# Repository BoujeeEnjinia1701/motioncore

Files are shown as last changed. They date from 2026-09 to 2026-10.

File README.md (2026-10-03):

# MotionCore

     

**Area:** Shared Components · **TRL:** 3 of 9 (proof of concept on paper) · **Value-engineering target:** USD 300 (estimated USD 293 for the kit) · **Difficulty:** 4 of 5

A standard controller and safety module (open motor controller, e-stop, speed limit and brake interlock) with a named reference hub motor, which the lab's mobility and automation designs bolt on rather than re-engineer.

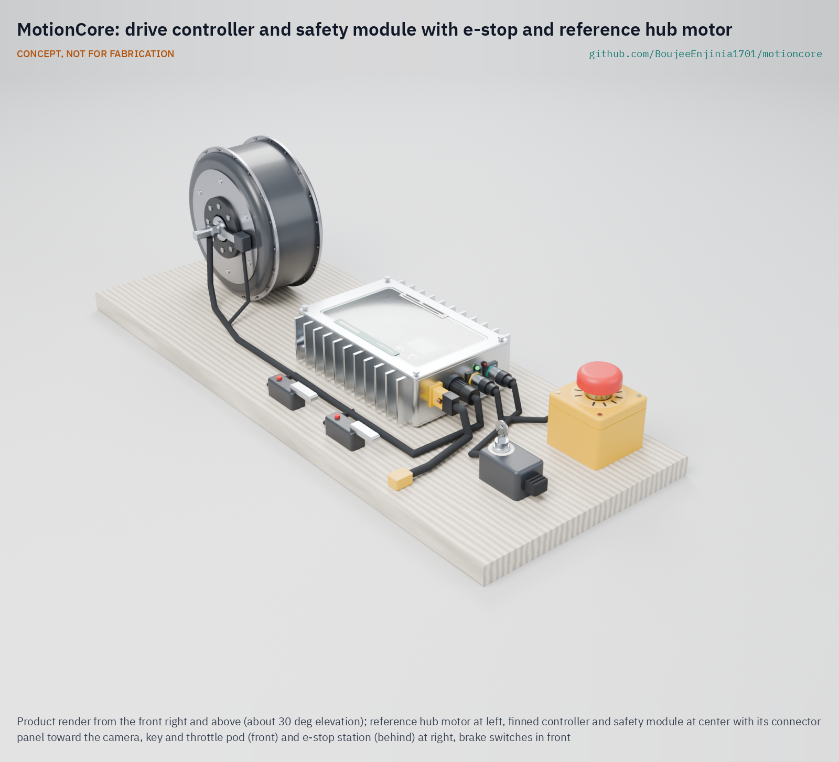
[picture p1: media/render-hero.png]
MotionCore: drive controller and safety module with e-stop and reference hub motor, product render


[Exploded render](media/render-exploded.png) · [Detail render](media/render-detail.png) · [Interactive 3D model](media/viewer.html) · [Concept blueprint (PDF)](media/concept-blueprint.pdf) · [General arrangement MTC-DWG-001 (PDF)](cad/drawings/MTC-DWG-001.pdf) · [Sizing note MTC-CAL-001](docs/04-calcs/01-sizing.md) · [Prototype build plan MTC-BLD-001](docs/05-build-plan.md) · [Design decisions MTC-DEC-001](docs/06-design-decisions.md) · [Review note](docs/REVIEW.md)

## Concept rationale

Standardizing the drive and safety chain lets the lab spend design effort on what is different about each vehicle, while every project inherits a reviewed safety function. MotionCore pairs an open VESC-class controller with a small independent supervisor and a DC contactor: the controller does the motor control it is already good at, and the supervisor and a hardwired emergency stop loop provide the second channel that low-cost controllers lack.

Keeping it open and garage-buildable matters because the people most likely to build small electric machines are makers, students and small workshops. Every part is sold off the shelf, the safety loop can be checked with a multimeter, and the interface is documented so that a host project, or anyone else, can reuse the module without closed tools.

## Burning platform

Light electric vehicles and small machines are spreading faster than the engineering support behind them. Almost 10 million electric two-wheelers were sold worldwide in 2025, about 14 % of all two-wheeler sales ([IEA Global EV Outlook 2026](https://www.iea.org/reports/global-ev-outlook-2026/trends-in-other-ev-modes)). In the United States, the Consumer Product Safety Commission estimates about 698,500 emergency department visits linked to micromobility products from 2017 through 2024 and records 533 deaths ([CPSC](https://www.cpsc.gov/s3fs-public/Micromobility_Products-Related_Deaths_Injuries_and_Hazard_Patterns_2017-2024.pdf)); most are crashes, which show how many people now ride and work beside small electric drives.

In workplaces, moving vehicles and machinery remain leading causes of death. In Great Britain, 24 of the 126 workers killed in 2025/26 were struck by a moving vehicle and 10 died in contact with moving machinery (provisional figures, [HSE](https://www.hse.gov.uk/STATISTICS/fatals-overview.htm)). An emergency stop that works without software, a speed limit that does not depend on one controller and a drive that never restarts by itself are basic protections, yet small builds often skip them.

## Where it could be used

### By industry

| Industry | Use |
| --- | --- |
| Warehousing and logistics | Drive and stop chain for powered pallet jacks, carts and tugs at walking pace (as in PalletPilot) |
| Last-mile delivery | Assist drives for cargo trailers, cargo bikes and stair-climbing hand trucks (CargoMule, StepClimber) |
| Agriculture | Small electric field carts, orchard platforms and barrows with a reliable stop |
| Solar operations and maintenance | Panel-cleaning robots and equipment carts on solar farms |
| Education and makerspaces | Teaching safe drive design with an open, inspectable safety loop |
| Rural transport | Bicycle conversion kits and shared-pack vehicles (SunSpoke with SwapCell) |

### By country or region

| Country or region | Why it matters there |
| --- | --- |
| United States | Micromobility injuries are tracked closely and rising; CPSC records 310 e-bike deaths from 2017 through 2024 ([CPSC](https://www.cpsc.gov/s3fs-public/Micromobility_Products-Related_Deaths_Injuries_and_Hazard_Patterns_2017-2024.pdf)) |
| European Union | Pedal-assist up to 250 W with a 25 km/h cutoff is excluded from type approval ([Regulation (EU) No 168/2013](https://eur-lex.europa.eu/legal-content/EN/TXT/PDF/?uri=CELEX%3A32013R0168)), so an independent speed limit matters for small builders |
| China | More than 7 million electric two-wheelers sold in 2025, over 55 % of the market ([IEA](https://www.iea.org/reports/global-ev-outlook-2026/trends-in-other-ev-modes)) |
| India | Almost 800,000 electric three-wheelers sold in 2025, almost 70 % of three-wheeler sales, many built and serviced by small workshops ([IEA](https://www.iea.org/reports/global-ev-outlook-2026/trends-in-other-ev-modes)) |
| Vietnam | About 735,000 electric two-wheelers sold in 2025, more than 20 % of the market ([IEA](https://www.iea.org/reports/global-ev-outlook-2026/trends-in-other-ev-modes)) |
| Kenya | Electric two-wheeler sales more than tripled in 2025 to over 25,000, around 15 % of new two-wheeler registrations, driven by motorcycle taxi riders ([IEA](https://www.iea.org/reports/global-ev-outlook-2026/trends-in-other-ev-modes)) |

## What sparked the idea

The idea traces back to a 2006 recall. The U.S. Consumer Product Safety Commission and Segway recalled about 23,500 Segway personal transporters because the machine could unexpectedly apply reverse torque to its wheels and throw the rider; six injuries to heads and wrists were reported, and the fix was a software upgrade ([CPSC recall notice](https://www.cpsc.gov/Recalls/2006/segway-inc-announces-recall-to-repair-segway-personal-transporters)). The recall shows how the safety of a small electric vehicle can hinge on one controller's software. MotionCore starts from the opposite assumption: the controller may misbehave, so an emergency stop that needs no firmware, a speed check on a separate sensor and a brake interlock sit beside it, and every host that bolts the module on inherits them.

## Problem

Each vehicle or machine concept re-specifies the same drive train and safety logic, and small teams rarely have time to get the emergency stop, speed limit and brake interlock right.

## Concept

A standard controller and safety module (open motor controller, e-stop, speed limit and brake interlock) with a named reference hub motor, which the lab's mobility and automation designs bolt on rather than re-engineer.

A finned module, 240 x 168 x 69 mm, holds an open VESC-class controller, a safety supervisor, a DC contactor and a precharge and fuse block. The emergency stop opens the contactor through a hardwired loop that works without any firmware, the speed limit is checked twice (controller and supervisor, each with its own speed signal), and the drive never restarts until the operator resets it. It runs from 20 to 60 V packs (24, 36 and 48 V classes), including SwapCell and CellGuard-managed 16S LiFePO4, and reads SwapCell or CellGuard faults over CAN.

The TRL 3 sizing note (MTC-CAL-001) gives, on paper: 250 W continuous at 40 °C ambient with about 47 °C on the case; 350 W on 24 V packs at about 56 °C, under the 60 °C limit thanks to a contactor coil economizer; motor power removed within 74 ms of an e-stop in the worst case; and an estimated MotionCore kit cost of USD 297 against a value-engineering target of USD 300 (USD 3 under), with the USD 70 reference motor costed to each host. The module weighs about 1.92 kg, inside its 2.0 kg limit. All figures are estimates, not measurements.

Full design precis: [docs/02-concept.md](docs/02-concept.md)

## Key components

- Reference 250 W geared hub motor, named in the interface and costed to each host (hosts may fit another motor within the rating)
- Open-source motor controller (VESC class, 20 to 60 V input)
- Safety supervisor board with its own speed sensor
- Hardwired twin-channel emergency stop and DC contactor, with precharge and main fuse
- Brake interlock switches
- Key switch and throttle pod (command input; CAN for host computers)
- Finned aluminum tube on a floor plate that doubles as the heat sink, on four M6 rivet-nut mounts
- Wiring harness with keyed connectors

The priced bill of materials is in [bom/bom.csv](bom/bom.csv); the parametric model is `cad/src/model.py`, with STEP and STL exports in `cad/step/` and `cad/stl/`.

## Building the prototype

The first prototype is the module bolted to a plywood bench board through its own mounting points, with the reference hub motor held by its axle in two slotted uprights so the wheel turns clear of the board, the e-stop station beside it and the brake levers and key and throttle pod on a short handlebar. The [prototype build plan](docs/05-build-plan.md) shows every component and every assembly step in pictures drawn from the model, with the checks and safety stops. Making the concept buildable changed how some parts are made and fixed, not what MotionCore does: the walls and fins are a cut length of finned extrusion on a separate floor plate, the sockets go straight through the end wall and a small fifth socket brings in the speed sensor ([MTC-DDR-003](docs/decisions/0003-design-for-construction.md)). Decisions still open are in the [design decisions register](docs/06-design-decisions.md).

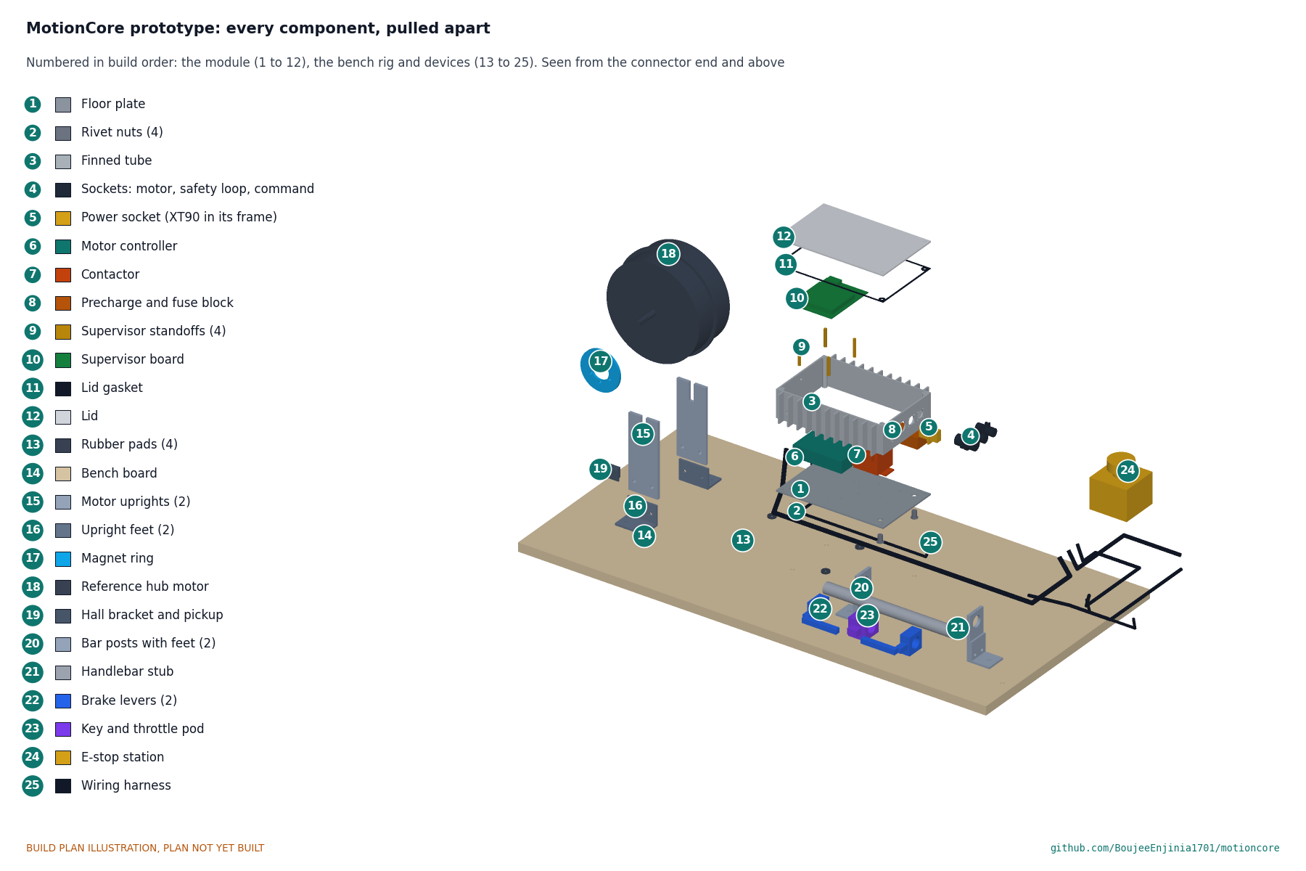
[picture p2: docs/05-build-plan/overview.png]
MotionCore prototype: every component pulled apart and numbered in build order


## Safety

> Moving machinery and stored electrical energy: guard all rotating parts, test the emergency stop before every run and limit speed during development, with the wheel off the ground for first runs. The safety functions are unverified paper designs until tested. A category 0 stop removes drive power but does not brake, so every host needs brakes that work unpowered. Never bridge the safety loop. Bus capacitors hold charge after disconnection, and the enclosure can reach about 60 °C, more in direct sun. The main fuse must be rated for the full DC pack voltage. Lithium cells can overheat, vent and burn. Use protected cells or LiFePO4, fuse every pack, charge only within the cell maker's limits and never leave a first build charging unattended. MotionCore is a research prototype, not certified to any machinery or vehicle standard. See [docs/02-concept.md](docs/02-concept.md#safety).

## Repository layout

| Folder | Contents |
| --- | --- |
| `docs/` | Problem, concept, requirements, calculations and design decisions |
| `cad/src/` | build123d Python source, the source of truth for all geometry |
| `cad/step/`, `cad/stl/` | Exported models for FreeCAD, other CAD tools and printing |
| `cad/drawings/` | 2D sketches and dimensioned drawings |
| `bom/` | Bill of materials |
| `electronics/` | KiCad schematics and PCB layouts |
| `firmware/` | Microcontroller code |
| `media/` | Renders, perspectives and photos |
| `build-log/` | Dated prototyping notes |

## Documentation

Controlled documents follow the portfolio [documentation standard](.kit/STANDARDS.md). Each carries a document ID (MTC-PRC-001 for the precis), a version and a revision history. Branded PDFs are built with `python .kit/render.py` and attached to GitHub Releases when a document is tagged, for example `MTC-PRC-001/v1.0`.

## Credits

Designed by Amish Chadha. See [CONTRIBUTORS.md](CONTRIBUTORS.md) for roles. To cite this design, use [CITATION.cff](CITATION.cff) (GitHub shows it as "Cite this repository").

AI assistance (Claude) was used to accelerate concept renders, prototype documentation and first-pass sizing calculations. Design direction and all decisions are Amish Chadha's, recorded in this repository's decision records (`docs/decisions/`).

## Licenses

- **Hardware** (CAD, drawings, BOM, electronics): [CERN-OHL-S v2](LICENSE)
- **Software** (firmware, scripts, notebooks): [MIT](LICENSE-SOFTWARE)

A project of the [Design Molecule](https://designmolecule.com) lab.

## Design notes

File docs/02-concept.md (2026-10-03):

---
doc_id: MTC-PRC-001
title: MotionCore design precis
project: MotionCore
doc_type: Design precis
version: "0.7"
status: Draft
date: '2026-10-02'
author: Amish Chadha
license: CERN-OHL-S-2.0
revisions:
- version: "0.1"
  date: '2026-09-25'
  author: Amish Chadha
  change: Initial scaffold
- version: "0.2"
  date: '2026-09-25'
  author: Amish Chadha
  change: Populate to TRL 2 (architecture, components, interface draft, first-order numbers, safety, open questions)
- version: "0.3"
  date: '2026-09-25'
  author: Amish Chadha
  change: TRL 3. Design choices adopted for TRL 3 pending Amish's review (MTC-DDR-001); motor costed to hosts; numbers checked against MTC-CAL-001; two CAN buses, precharge closure at 0.6 s, fuse and contactor criteria; model, drawing MTC-DWG-001 and media refreshed
- version: "0.4"
  date: '2026-09-25'
  author: Amish Chadha
  change: Recommendations accepted by Amish (DDR-002). Input 20 to 60 V, controller overvoltage fault 66 V, fuses rated 60 V DC or more, module mass limit 2.0 kg, XT90 provisional pending a sealed-connector evaluation; TRL 3 engineering proposals confirmed
- version: "0.5"
  date: '2026-10-01'
  author: Amish Chadha
  change: Constructable design (MTC-DDR-003, Draft, open for Amish's review). Finned tube on a floor plate, sockets through the end wall, M8 speed socket, bench rig for the prototype; size, mass and cost updated; budget as a value-engineering target
- version: "0.6"
  date: '2026-10-02'
  author: Amish Chadha
  change: "Decisions of 2026-10-02: MTC-DDR-003 accepted; interface v0.2; economizer; sealed connector rule; dual-motor and brushed hosts; license review timing"
- version: "0.7"
  date: '2026-10-02'
  author: Amish Chadha
  change: 'Interface v0.2 issued (speed socket, pin-out, host arrangements); coil economizer in the design; R2 and R9 met on paper; figures per MTC-CAL-001 v0.5'
---

# MotionCore design precis

## Summary

MotionCore is a finned aluminum module, 240 x 168 x 69 mm, that sits between a host's battery pack and its motor. Inside are an open VESC-class motor controller, a small safety supervisor board, a DC contactor and a precharge and fuse block. Outside, one keyed connector set on its end wall links it to a named reference 250 W geared hub motor, a twin-channel emergency stop, two brake switches, a key and throttle pod and an independent speed sensor. The emergency stop opens the contactor through a hardwired loop, so it works even if both processors fail. The speed limit is held twice: once in the controller and once in the supervisor, which reads its own sensor.

The TRL 3 sizing note (MTC-CAL-001) gives, on paper: 6.9 A from a SwapCell pack in the reference case, about 47 °C on the case, motor power removed within 74 ms of an e-stop (worst case), and an estimated MotionCore kit cost of USD 297 against a value-engineering target of USD 300 (USD 3 under), with the USD 70 reference motor costed to each host. The module weighs about 1.92 kg, inside the 2.0 kg limit Amish set in place of 1.5 kg (R12 met, 0.08 kg margin), and the 350 W heavy case on a 24 V pack stays under the 60 °C case limit (about 55.6 °C) because a coil economizer holds the contactor at about 1 W (R9 met on paper, in shade). The design was made buildable in MTC-DDR-003 (Draft, open for Amish's review) without changing what it does; the prototype build plan is MTC-BLD-001. The design choices below were decided by Amish on 2026-09-25, going with the recommendations (MTC-DDR-001 and MTC-DDR-002).

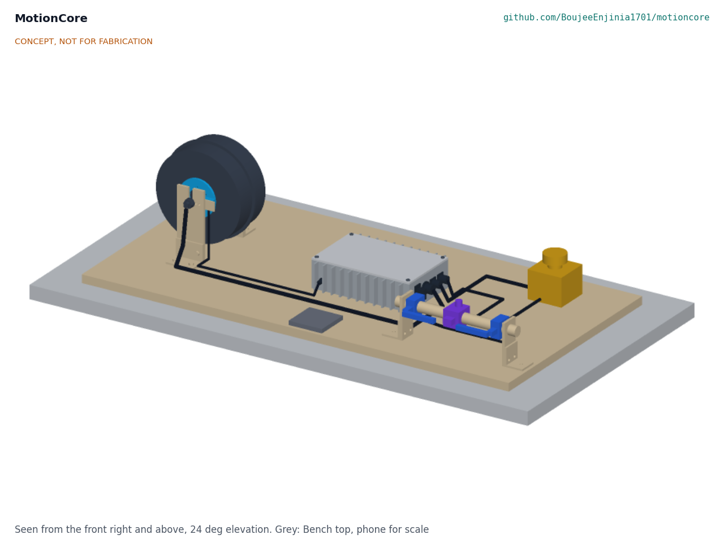
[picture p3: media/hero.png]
MotionCore concept


*Figure 1. Reference kit laid out on a bench: module (center), reference hub motor (left), e-stop station, key and throttle pod and brake switches (right). Massing-plus model, not for fabrication.*

## How it works

1. **Power up.** The pack connects through an anti-spark plug and the main fuse. The supervisor, fed from the pack through its own 18 to 75 V buck, closes the precharge path, waits six time constants (0.6 s) and checks that the controller reports at least 90 % of the pack voltage; only then may the contactor close. On a SwapCell pack the supervisor first sends the SwapCell host heartbeat (host type 0, vehicle, mode 2).
2. **Enable.** The contactor coil is powered through the safety loop: e-stop channel A, the enable key and a supervisor-controlled switch, all in series. E-stop channel B goes to the supervisor as a separate input. The supervisor closes its switch only if the throttle reads zero, both brake switches are released, the controller reports no fault on CAN and the BMS reports no fault. This gives R4: no automatic restart.
3. **Drive.** The host's command (throttle, pedal-assist sensor or CAN set-point from a host computer) goes to the supervisor, which passes a limited command to the controller over an internal CAN bus. The controller runs the motor with its own current, temperature and speed limits. Its battery current limit is set to the lower of the host setting and the pack's allowed discharge current.
4. **Watch.** The supervisor times the pulses from a magnet ring on the wheel hub (item 12), independent of the controller's own speed estimate. It also watches the brake switches, command timeouts, temperatures and the BMS fault frames on the external CAN bus.
5. **Stop.** A brake switch or a minor fault sets the controller command to zero within 200 ms (R5, R7). Overspeed, a failed controller heartbeat or any safety-loop fault opens the contactor (stop category 0 in IEC 60204-1 terms). Pressing the e-stop opens the coil circuit directly, without software, and at the same time tells the supervisor to command zero current. A host with a spring-applied brake has that brake powered from the same loop, so it clamps when the loop opens.

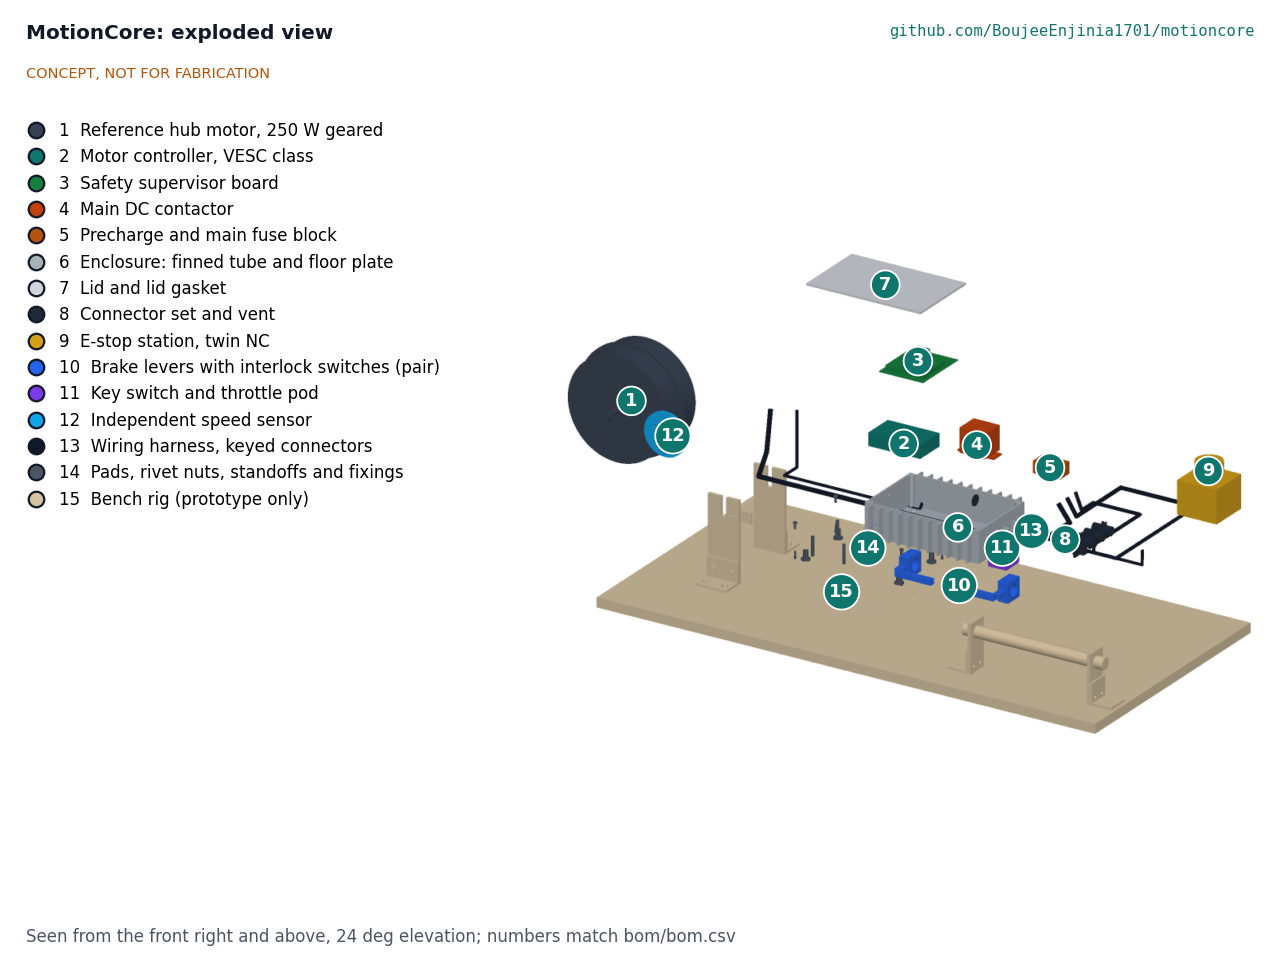
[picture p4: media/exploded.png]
Exploded view


*Figure 2. Exploded view. Numbers match `bom/bom.csv`.*

## Main components

*Table 1. Main components. Item numbers match the BOM and Figure 2.*

| Item | Component | Role |
| --- | --- | --- |
| 1 | Reference hub motor, 250 W geared | Named reference motor in the interface; costed to each host, which may substitute another motor within R2 |
| 2 | Motor controller, VESC class, 75 V stage | Field-oriented control, current and temperature limits, speed limit, CAN; overvoltage fault set to 66 V |
| 3 | Safety supervisor board | Microcontroller with two CAN buses, 18 to 75 V buck for the coil and logic, independent speed input, throttle, brake and e-stop channel B inputs, contactor enable switch, precharge switch, fault log |
| 4 | Main DC contactor, 100 A | Removes all power to the controller on e-stop or fault; coil in the safety loop; breaks at least 50 A at 60 V DC; releases within 50 ms with a 24 V Zener suppressor |
| 5 | Precharge and main fuse block | 100 Ω precharge resistor and switch; main fuse rated 60 V DC or more: 20 A for 36 and 48 V hosts, 40 A for 24 V hosts |
| 6 | Enclosure: finned tube and floor plate | Heat sink for the controller: a cut length of finned extrusion on a 3 mm floor plate; four M6 rivet nuts on a 180 x 100 mm pattern (MTC-DDR-003) |
| 7 | Lid and lid gasket | Flat 3 mm lid on a 1 mm EPDM gasket, four screws into the corner ports |
| 8 | Connector set and vent | Power in, motor, safety loop and command sockets through the end wall; M8 speed sensor socket in the side wall; membrane vent |
| 9 | E-stop station, twin NC | Red mushroom head on yellow, two normally closed contact blocks, twist release |
| 10 | Brake levers with interlock switches (pair) | Normally closed switches in each brake lever (a host may use its own lever or pedal switches) |
| 11 | Key switch and throttle pod | Enable key (reset after a stop) and a hall-effect throttle |
| 12 | Independent speed sensor | Magnet ring and Hall pickup, read only by the supervisor |
| 13 | Wiring harness, keyed connectors | Pre-made leads from the sockets to each device; 4 mm² pack leads for 24 V hosts |
| 14 | Pads, rivet nuts, standoffs and fixings | Rubber pads on the host mounting points, rivet nuts, standoffs, thermal pad, screws |

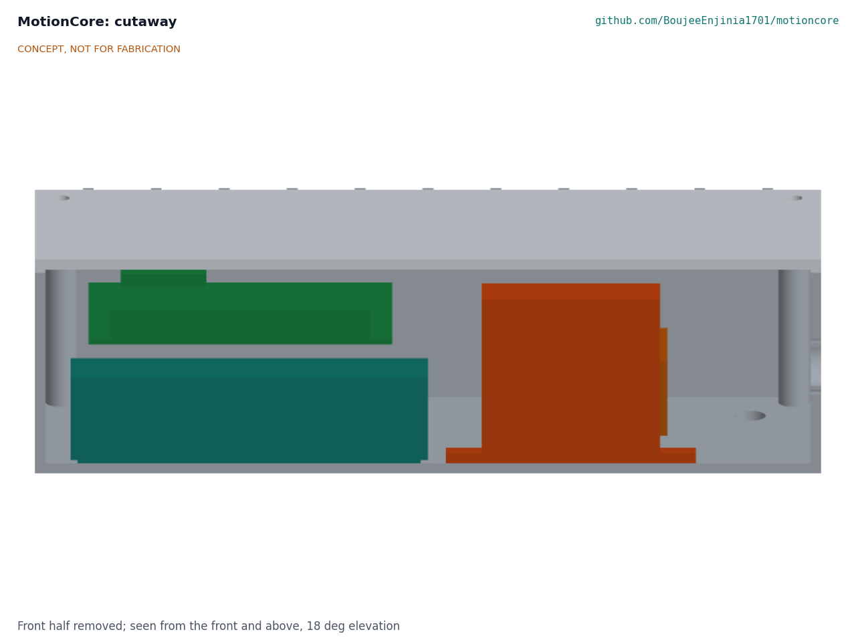
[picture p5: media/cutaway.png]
Cutaway


*Figure 3. Cutaway through the module: supervisor board on standoffs above the controller (left), contactor (center) and precharge and fuse block (right).*

### Interface (MotionCore interface v0.2)

*Table 2. Connector set (item 8). Interface v0.2 was issued on 2026-10-02 (decided by Amish, MTC-DDR-003 A1): the four sockets of v0.1 (decided 2026-09-25, MTC-DDR-001 item 6) in the +X end wall, seen from the socket side, plus an M8 4-pin speed socket in the side wall. The power connector is a sealed single-pole pair, part to be chosen (MTC-DDR-004); the XT90 shown is for the bench prototype only.*

| Connector | Type | Lines |
| --- | --- | --- |
| Power in | XT90 anti-spark plug (bench prototype only; sealed single-pole pair to follow, MTC-DDR-004) | Pack positive and negative, 20 to 60 V |
| Motor | 9-pin waterproof e-bike motor plug | Three phases, Hall sensors, motor temperature |
| Safety loop | M12 8-pin A-coded | E-stop channels A and B, brake switches A and B, enable key, brake coil output |
| Command | M12 5-pin B-coded, so it cannot mate with the safety loop | Throttle or pedal-assist, CAN high and low (external bus, 250 kbit/s), 5 V, ground |
| Speed | M8 4-pin A-coded, in the side wall | 5 V, ground, speed pulses from the independent speed sensor |

*Table 2a. Pin-out of the three signal sockets (as build plan Table 3).*

| Socket | Pin | Line |
| --- | --- | --- |
| Safety loop (M12, 8-pin A) | 1 | Loop supply, 12 V out to e-stop channel A |
| | 2 | Loop return, after e-stop channel A and the key, to the contactor coil |
| | 3 | E-stop channel B (to ground when the e-stop is not pressed) |
| | 4 | Brake switch A (to ground when the lever is released) |
| | 5 | Brake switch B (to ground when the lever is released) |
| | 6 | Brake coil output, 12 V, for a host's spring-applied brake; live only while the loop is closed |
| | 7 | Ground |
| | 8 | Not connected |
| Command (M12, 5-pin B) | 1 | +5 V for the throttle |
| | 2 | Throttle signal, 0.8 to 4.2 V |
| | 3 | Ground |
| | 4 | CAN high, external bus |
| | 5 | CAN low, external bus |
| Speed (M8, 4-pin A) | 1 | +5 V |
| | 2 | Not connected |
| | 3 | Ground |
| | 4 | Speed pulses |

The module mounts on four M6 studs on a 180 x 100 mm pattern through rubber isolation pads (drawing MTC-DWG-001). The command connector carries the external CAN bus to a SwapCell pack or a CellGuard BMS; the controller sits on a separate internal bus. The SwapCell INTERLOCK coding resistor belongs in the host's pack receptacle, not in MotionCore. Interface v0.2 has five sockets, which is one more than v0.1: CargoMule, the first host, is told of the speed socket (see the review note).

*Host arrangements (decided 2026-10-02).* Dual-motor hosts such as PalletPilot fit two controllers on one supervisor, with one safety loop and one contactor feeding both controllers. Brushed-motor hosts such as StepClimber use the VESC-class controller's DC motor mode, and need a different power stage only if the motor needs more current than the controller is rated for.

## Numbers (MTC-CAL-001)

All numbers are paper estimates printed by `docs/04-calcs/sizing.py`; nothing is measured.

### Currents and fuse

At 250 W shaft power the pack supplies about 322 W: 6.9 A at 46.8 V (SwapCell) and 8.4 A at 38.4 V (CargoMule's 12S LiFePO4 pack). The heavy case, 350 W on 25.6 V, draws 17.7 A, and 22.9 A at 20 V. For 750 W over 10 s the pack delivers 21.9 A on SwapCell and 40.9 A on 8S LiFePO4. A 20 A fuse suits 36 and 48 V hosts and a 40 A fuse suits 24 V hosts, both rated for 60 V DC or more with at least 1 kA breaking capacity (prospective short-circuit currents are about 470 to 860 A for the three packs calculated; a CellGuard 16S pack is to be checked once its resistance is known). The 100 A contactor has a wide margin on continuous current; its selection criteria are breaking at least 50 A at 60 V DC and releasing within 50 ms.

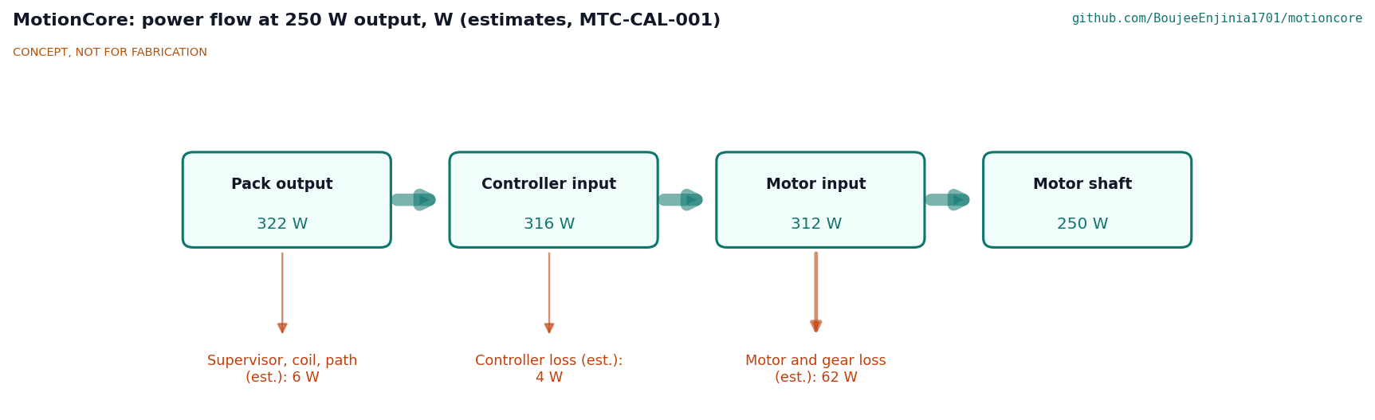
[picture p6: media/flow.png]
Power flow


*Figure 4. Estimated power flow at 250 W shaft output on a SwapCell pack (MTC-CAL-001).*

### Emergency stop timing

The e-stop contacts open the coil circuit directly. With a 24 V Zener across the coil, the modeled time to remove motor power is about 37 ms; using the 50 ms release limit that the contactor must meet, the worst case is about 74 ms, inside the 100 ms target of R3. In 74 ms a host at 25 km/h (6.9 m/s) travels about 52 cm and a walk-behind machine at 1.5 m/s about 11 cm. After that the host stops on its own brakes. A plain diode suppressor would lengthen the release; the Zener is part of the design.

### Precharge

With about 1,000 µF of bus capacitance and a 100 Ω resistor, the time constant is 0.1 s. The contactor closes after 0.6 s, when the residual difference is under 0.14 V and the closure current is at most 1.3 A. The peak precharge current is 0.55 A and the resistor absorbs about 1.5 J per start. A 1 s timeout protects the resistor if the bus is shorted.

### Thermal

The enclosure sheds about 1.16 W per kelvin of rise in still air (clear anodized, shaded).

- **Reference case:** about 6.5 W of heat in steady state (controller 4.2 W, auxiliary supply and held coil 1.9 W, power path 0.4 W at minimum pack voltage): about 47 °C at 40 °C ambient. R9 met.
- **Heavy case at 350 W:** about 16.5 W, about 55.6 °C on the walls and 56.9 °C on the floor plate, which joins the finned tube through a sealant film (MTC-CAL-001 v0.5). Met with about 4 K of margin on the walls, which would go if the controller runs hotter than modeled (62 to 68 °C in the sensitivity cases); R9 is **met on paper**, in shade. At 500 W the case would reach about 65 °C, which is why the heavy case is derated.
- **Coil economizer.** The contactor coil takes 4 W and was about half of the reference-case heat. An economizer module on the supervisor carrier board (BOM line 3), decided on 2026-10-02, applies full voltage for 0.5 s and then holds the coil at about 1 W. It is wired so the safety loop breaks the coil supply upstream of it, so a stop still drops the contactor within the 50 ms the e-stop timing assumes; its output capacitor is limited to 100 uF and the 74 ms worst case includes it.

### Speed sensing

With eight magnets and a 20 in wheel (1.57 m circumference), the supervisor sees about 7.6 pulses per second at 1.5 m/s and about 35 at 25 km/h. It times each pulse period rather than counting pulses, because a count over 0.5 s is too coarse at walking pace. Magnet placement jitter of about 2 % leaves a fivefold margin to the 10 % overspeed threshold, and a sustained overspeed opens the contactor in about 0.6 to 0.7 s.

### CAN and bus voltage

The internal bus (supervisor and controller, 500 kbit/s) runs at about 11 % load and the external bus (pack or BMS, 250 kbit/s) at about 3 %. Regeneration is off unless a host enables it, in which case the supervisor requests SwapCell mode 4 with a host charge limit. The controller's overvoltage fault sits at 66 V, above a full CellGuard 16S pack (58.4 V); if the contactor opens during regeneration it keeps the bus near 67.8 V, inside its 75 V rating. Direct-drive motors must not be pushed beyond about 1.25 times their no-load speed at 60 V without a bus clamp.

### Size, mass and cost

- Module: 240 x 168 x 69 mm; about 1.92 kg, of which the enclosure metal is about 1.0 kg. R12 (2.0 kg, relaxed from 1.5 kg by MTC-DDR-002) is met with 0.08 kg of margin. Kit: about 5.3 kg with the reference motor, 2.9 kg without.
- Cost: value-engineering target USD 300. Estimated cost of the constructable MotionCore kit (BOM items 2 to 14): USD 297 (USD 3 under the target, including USD 4 for the coil economizer module); the reference motor adds USD 70 and is costed to each host, and the prototype's bench rig USD 35 (`bom/bom.csv`).

## Key design choices

All choices below were decided by Amish on 2026-09-25, going with the recommendations (MTC-DDR-001, MTC-DDR-002).

1. **VESC-class controller rather than a custom power stage.** It is open, widely sold, already handles DC, BLDC and FOC motors and has CAN. The drawback is that it has no separate safety channel, which the supervisor and contactor provide.
2. **Contactor as the power-removal element.** A DC contactor is cheap, visible and testable with a multimeter. Safe Torque Off on the gate drivers would be faster and wear-free but needs a custom controller.
3. **Separate supervisor with its own speed sensor.** This gives two independent channels for speed limiting, following the structure of ISO 13849-1 Category 3 without claiming a performance level.
4. **Stop category 0 by default.** Removing power is simplest to verify. Category 1 (brake electrically, then open the contactor) is a per-host option for heavier hosts.
5. **Wide input range (20 to 60 V).** One module serves 24, 36 and 48 V hosts, including CellGuard's 16S LiFePO4 packs at 58.4 V full; DustRunner's 12.8 V system stays out of scope.
6. **Motor as a named reference part, costed to hosts.** The interface names the reference motor, but the USD 300 value-engineering target covers the module and devices only.
7. **Supervisor as SwapCell host and CellGuard reader.** The supervisor sends the SwapCell heartbeat and removes torque on a BMS fault.
8. **Heavy case derated to 350 W on 24 V packs.**
9. **Separate firmware.** Unmodified GPL-3.0 VESC firmware on the controller and MIT supervisor firmware on its own processor, linked only by CAN.

10. **Module mass limit 2.0 kg.** The enclosure stays as drawn, because it is the heat sink and R9 depends on it.
11. **TRL 3 engineering rules from MTC-CAL-001.** Two CAN buses on the supervisor, precharge closure at 0.6 s with a 90 % bus check, fuses rated for the full DC range with 1 kA breaking capacity, 4 mm² pack leads for 24 V hosts and a 24 V Zener coil suppressor. The fuse rating became 60 V DC and the controller overvoltage fault 66 V (instead of 58 V and 60 V) when R1 was raised to 60 V.
12. **Sealed power connector evaluated (MTC-DDR-004).** The XT90 stays in the model and drawing as the bench prototype's part until a sealed connector is chosen.

Decisions are recorded in [decisions/](decisions/).

## Safety

> **Safety:** MotionCore drives moving machinery from a lithium pack. Guard all rotating parts, test the emergency stop before every run and limit speed during development. The pack can deliver several hundred amperes into a short circuit (about 470 to 860 A for the host packs considered): fuse it with a fuse rated for the full DC voltage, use the anti-spark connector, and never work on the module with the pack connected. Bus capacitors can hold charge after disconnection; wait and measure before touching the board. The enclosure can reach about 50 to 60 °C in hot conditions, more in direct sun. Opening a contactor under DC load can arc; use a contactor rated for DC breaking at the full pack voltage. Lithium cells can overheat, vent and burn: use packs with a BMS, fuse every pack and never leave a first build charging unattended.

- **Unverified safety function.** Until tested at TRL 4, which is on hold, the e-stop timing, overspeed trip and restart inhibit are paper claims. First runs should be on a bench with the wheel off the ground and a second person at the e-stop.
- **Coasting after a stop.** A category 0 stop removes drive power but does not brake. The host must have brakes that stop it unpowered, and walk-behind hosts need spring-applied brakes.
- **Back-EMF.** A direct-drive motor pushed faster than about 1.25 times its no-load speed (at 60 V) can raise the bus above 75 V through the controller's MOSFET body diodes, even with the contactor open. Geared hubs with a freewheel avoid this; direct-drive hosts need a speed limit or a bus clamp.
- **Configuration errors.** The speed limit depends on the wheel circumference and magnet count stored in the supervisor. A wrong value moves the limit; the fault chart must say so.
- **Misuse of the interface.** If the safety loop is bridged with a jumper, every protection is lost. The loop connector is keyed and the fault chart must say so plainly.
- **No certification.** MotionCore is a research prototype. It is not certified to ISO 13849, IEC 60204-1, EN 15194 or any vehicle rule, and it does not make a host compliant.

## Open questions

- Dual-motor hosts (PalletPilot): decided 2026-10-02, two controllers on one supervisor, with one safety loop and one contactor feeding both, so a stop removes torque from both wheels at once.
- Brushed motors (StepClimber): decided 2026-10-02, the controller's DC motor mode; a different stage only if StepClimber's motor needs more current than the controller is rated for.
- Which sealed power connector replaces the unsealed XT90 (R10): the paper evaluation is written (MTC-DDR-004); it recommends an industrial IP67 single-pole pair, two receptacles with different key coding, and chooses no part, because the rule (keyed, IP67 when mated, 40 A or more continuous at 60 V DC, no exposed live contacts on the pack side) has to be checked against a named part's datasheet at the parts purchase. The XT90 stays for the bench prototype only; R10 stays at risk.
- Contactor coil economizer: decided 2026-10-02 and now in the design: a module on the supervisor carrier board (BOM line 3, USD 4), wired after the safety loop's break in the coil supply; heavy case 55.6 °C on the walls instead of 58.4 °C (MTC-CAL-001 v0.5).
- Whether a pack in SwapCell legacy discharge accepts a heartbeat and moves to mode 2 without opening its output; raised with SwapCell.
- License boundary between the VESC firmware (GPL-3.0) and the MIT supervisor firmware: the short written review is done (MTC-DDR-005), with a firmware readme to be written before any firmware is published; a lawyer only if a commercial partner will ship the module (decided 2026-10-02).

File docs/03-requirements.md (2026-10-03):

---
doc_id: MTC-REQ-001
title: MotionCore requirements
project: MotionCore
doc_type: Requirements
version: "0.7"
status: Draft
date: '2026-10-02'
author: Amish Chadha
license: CERN-OHL-S-2.0
revisions:
- version: "0.1"
  date: '2026-09-25'
  author: Amish Chadha
  change: Initial scaffold
- version: "0.2"
  date: '2026-09-25'
  author: Amish Chadha
  change: First measurable requirements for TRL 2, with status against the concept estimates
- version: "0.3"
  date: '2026-09-25'
  author: Amish Chadha
  change: TRL 3. R2 heavy case relaxed to 350 W and R14 redefined to the MotionCore kit without the motor (MTC-DDR-001, adopted for TRL 3 pending Amish's review); status column from MTC-CAL-001
- version: "0.4"
  date: '2026-09-25'
  author: Amish Chadha
  change: Recommendations accepted by Amish (DDR-002). R1 upper bound 58 to 60 V; R12 mass limit 1.5 to 2.0 kg; status from MTC-CAL-001 v0.2
- version: "0.5"
  date: '2026-10-01'
  author: Amish Chadha
  change: Constructable design (MTC-DDR-003); status from MTC-CAL-001 v0.3 (R9, R11, R12); R14 reported against the value-engineering target; no status changed
- version: "0.6"
  date: '2026-10-02'
  author: Amish Chadha
  change: "Decisions of 2026-10-02 noted: interface v0.2 (R11), economizer (R9), sealed connector evaluation (R10), license review timing (R13); no status changed"
- version: "0.7"
  date: '2026-10-02'
  author: Amish Chadha
  change: 'Status from MTC-CAL-001 v0.5: R2 and R9 re-rated to met on paper with the coil economizer; R3, R12 and R14 figures updated'
---

# MotionCore requirements

These requirements are checked by calculation in MTC-CAL-001 v0.5, against the constructable design of MTC-DDR-003. Four targets have changed since TRL 2, all decided by Amish on 2026-09-25 (MTC-DDR-001 and MTC-DDR-002): the heavy case in R2 is 350 W instead of 500 W; R14 covers the MotionCore kit without the reference motor; the upper bound of R1 is 60 V instead of 58 V, so that CellGuard's 16S LiFePO4 packs are covered; and the mass limit in R12 is 2.0 kg instead of 1.5 kg, because the enclosure is also the heat sink. No requirement has been verified by test.

The **reference case** used throughout is a 250 W geared hub motor on a 48 V (46.8 V nominal) SwapCell pack at 40 °C ambient. The **heavy case** is 350 W continuous on a 25.6 V (8S) LiFePO4 pack at 40 °C ambient.

On paper, twelve requirements are met and none is not met. R10 is **at risk**; R11 cannot be verified at TRL 3. R2 and R9 moved from at risk to met on paper on 2026-10-02 because the contactor coil economizer is now in the design. R12 is met with a margin of 0.08 kg.

*Table 1. Requirements.*

| ID | Requirement | Target | Verification (TRL 3 or later) | Status at TRL 3 (MTC-CAL-001) |
| --- | --- | --- | --- | --- |
| R1 | Supply range | Operate from 20 to 60 V DC (8S LiFePO4 to 13S lithium-ion and 16S LiFePO4, including SwapCell at 54.6 V full and CellGuard 16S at 58.4 V full); withstand 75 V transients from regeneration | Controller and contactor datasheets; bus voltage calculation | Met (design review): 75 V controller, 18 to 75 V auxiliary buck, bus peaks near 67.8 V with a 66 V controller overvoltage fault |
| R2 | Motor power | 250 W continuous in the reference case; 350 W continuous in the heavy case; 750 W for 10 s | Current and thermal calculation | Met on paper (re-rated 2026-10-02): 6.9 A, 17.7 A; 750 W peak 21.9 A on SwapCell, 40.9 A on 8S LiFePO4; the heavy case now holds with R9 |
| R3 | Hardwired emergency stop | Twin-channel normally closed e-stop wired in series with the contactor coil; motor power removed within 100 ms of actuation; works with the supervisor and controller both failed | Circuit review; contactor drop-out time from datasheet | Met on paper: 74 ms worst case, 37 ms modeled (including the coil economizer's output capacitor); unverified |
| R4 | No automatic restart | After an e-stop, power loss or fault, the drive stays off until the e-stop is released, the throttle is at zero and the operator cycles the enable key | Circuit and state-machine review | Met (design review); unverified |
| R5 | Brake interlock | Two brake switch inputs; drive torque removed within 200 ms of either switch opening; a spring-applied brake output released only while the safety loop is closed | Circuit review; supervisor timing budget | Met on paper: about 75 ms; unverified |
| R6 | Independent speed limit | Speed limit set in the controller and checked by the supervisor from a separate sensor; overspeed of more than 10 % for more than 0.5 s opens the contactor; defaults 25 km/h (pedal assist) and 1.5 m/s (walk-behind) | Firmware review; sensor resolution calculation | Met on paper: period timing, fivefold margin over magnet jitter, trip in 0.60 to 0.70 s; unverified |
| R7 | Fault reaction | Supervisor removes torque within 200 ms of: command timeout, throttle signal outside 0.5 to 4.5 V, loss of controller CAN heartbeat, over-temperature or BMS fault flag | Fault table review | Met on paper: about 170 ms worst (controller heartbeat), about 80 ms for a BMS fault; unverified |
| R8 | Precharge | Inrush at contactor closure under 5 A; bus ready within 1 s | Precharge calculation | Met: 0.55 A peak, 1.3 A at closure, ready in 0.6 s |
| R9 | Thermal | Enclosure surface 60 °C or less at 40 °C ambient in natural convection | Thermal calculation | Met on paper (re-rated 2026-10-02) in shade: reference case 47.0 °C; heavy case 55.6 °C on the walls and 56.9 °C on the floor plate with the contactor coil economizer in the design (BOM line 3); the sensitivity cases reach 62 to 68 °C, so the margin rests on the controller assumptions |
| R10 | Ingress and vibration | Enclosure and mated connectors IP65; survive road and stair vibration without loosening | Datasheets and design review | **At risk:** the XT90 power socket is not sealed; a sealed power connector is to be evaluated before interface v0.1 is frozen (MTC-DDR-002). Decided 2026-10-02: the paper evaluation is done now against a rule (keyed, IP67 mated, 40 A or more continuous at 60 V DC, no exposed live contacts on the pack side; first candidate class an industrial IP67 single-pole connector such as Amphenol's SurLok Plus), and the XT90 stays for the bench prototype only; vibration not analyzed |
| R11 | One interface | One documented connector set (power in, motor, sensors, safety loop, command) keyed against mis-mating; fitted to a new host in 2 h or less with hand tools | Interface document; timed fit at TRL 4 | Not verifiable at TRL 3: interface v0.2 decided on 2026-10-02 (MTC-DDR-003 A1): the four sockets of v0.1 drawn in MTC-DWG-001 Rev P3 plus an M8 4-pin speed sensor socket, with the pin-out of build plan Table 3 |
| R12 | Size and mass | Module within 250 x 170 x 70 mm; module mass 2.0 kg or less (1.5 kg before MTC-DDR-002) | Model and mass estimate | Met: 240 x 168 x 69 mm; about 1.92 kg, 0.08 kg margin |
| R13 | Open and repairable | Hardware under CERN-OHL-S-2.0; supervisor firmware MIT; controller firmware open source; fault log readable over USB without closed software | License review | Met (design review): separate programs on separate processors, CAN link only; the short written license boundary review is done (MTC-DDR-005), and a firmware readme is written before any firmware is published (decided 2026-10-02) |
| R14 | Cost | MotionCore kit (module and devices, BOM items 2 to 14) against a value-engineering target of USD 300 in parts (a hypothetical control target, not a limit); the reference motor is costed to each host | Priced BOM (`bom/bom.csv`) | USD 297 on indicative prices, USD 3 under the target (reference motor USD 70 extra) |

## Assumptions

- Motor efficiency about 80 % at rated load; controller losses from a component model (MTC-CAL-001 Table 1), which gives about 98 to 99 % controller efficiency; to be checked against datasheets once parts are chosen.
- Contactor release time 50 ms or less with a 24 V Zener coil suppressor; this is a selection criterion for the part.
- Enclosure conductance about 1.17 W/K from simplified natural convection and radiation correlations, clear anodized, shaded (MTC-CAL-001 section 4).
- The host provides mechanical brakes able to stop it with the motor unpowered. MotionCore removes drive power; it does not replace the host's brakes.
- The host carries out its own risk assessment. MotionCore targets are not a claimed ISO 13849 performance level.

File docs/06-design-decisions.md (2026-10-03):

---
doc_id: MTC-DEC-001
title: MotionCore design decisions register
project: MotionCore
doc_type: Design decisions register
version: "0.3"
status: Draft
date: '2026-10-02'
author: Amish Chadha
license: CERN-OHL-S-2.0
revisions:
  - version: "0.1"
    date: '2026-10-01'
    author: Amish Chadha
    change: Register opened with the build plan; open items from REVIEW.md, MTC-DDR-001 to 003 and the build work; budget treated as a value-engineering target
  - version: "0.2"
    date: '2026-10-02'
    author: Amish Chadha
    change: "Amish approved the recommendations for open decisions 1 to 9 (2026-10-02); moved to decisions made (MTC-DDR-003 accepted)"
  - version: "0.3"
    date: '2026-10-02'
    author: Amish Chadha
    change: 'Follow-ups carried out: economizer in BOM and model (kit USD 297); sealed connector evaluation and license boundary review written (MTC-DDR-004, MTC-DDR-005); item to confirm for the connector part'
---

# MotionCore design decisions register

Every design decision still to be made, and every decision made, in one place. Each decision is argued in full in its decision record under `docs/decisions/`; this register is the index Amish works from. The build plan (`docs/05-build-plan.md`) describes the design as it stands and does not list open decisions.

## Open decisions

None. All open decisions were decided on 2026-10-02.

## To confirm when parts are bought

| # | What to confirm | Why it matters | Source |
| --- | --- | --- | --- |
| 1 | A finned enclosure extrusion near 220 x 140 mm with 3 mm walls, vertical-running fins about 3 x 14 mm on a 19 mm pitch and four inside-corner screw ports; if none is stocked, a short custom run or a machined body | Sets the tube, the floor plate's corner holes and the thermal figures | MTC-DDR-003, P1 |
| 2 | The controller's mounting-hole pattern, flat base for the thermal pad, bus capacitance (about 1,000 µF) and MOSFET resistance | Sets the floor plate's controller holes and the precharge and thermal figures | MTC-CAL-001 section 1 |
| 3 | The contactor's foot holes, release time (50 ms or less with the Zener) and DC breaking rating (50 A at 60 V) | Sets the floor holes and the e-stop timing | MTC-CAL-001 section 5 |
| 4 | The reference motor's axle width (about 135 mm), axle flats (10 mm) and six-bolt disc mount | Sets the upright spacing and slot, and the magnet ring | MTC-DDR-003, P10, P11 |
| 5 | Brake levers with normally closed (not normally open) cut-off switches | The interlock expects a closed contact when released | MTC-PRC-001 item 10 |
| 6 | The M12 sockets come with 20 mm four-screw square flanges and the XT90 with a two-screw panel frame | Sets the end wall holes | MTC-DDR-003, P5 |
| 7 | The prospective short-circuit current of a CellGuard 16S pack against the fuse's 1 kA breaking capacity | Fuse choice for CellGuard hosts | MTC-CAL-001 section 3 |
| 8 | Whether a SwapCell pack in legacy discharge accepts a heartbeat and moves to mode 2 without opening its output | The supervisor is powered from the pack | `docs/REVIEW.md`, cross-repo actions |
| 9 | The sealed power connector part: the evaluation (MTC-DDR-004) recommends an industrial IP67 single-pole pair; check one named part's datasheet against the rule (keyed, IP67 mated, 40 A or more at 60 V DC, no exposed live contact), then change the end wall holes, socket frame and BOM line 8 | Sets R10 and the end wall of the tube | MTC-DDR-004 |
| 10 | The coil economizer module: a 12 V, 1 A part with full voltage for 0.5 s, then about 1 W hold and an output capacitor of 100 uF or less | Sets the 1 W hold figure of R9 and the 74 ms of R3 | MTC-CAL-001 v0.5 |

## Value engineering

Value-engineering target: USD 300 (a hypothetical control target, not a limit). Estimated cost of the constructable design: USD 297 for the MotionCore kit, items 2 to 14 (USD 3 under the target). The reference hub motor (USD 70) is costed to each host, and the bench rig (USD 35) belongs to the prototype only. Main cost drivers and savings worth trying:

- The largest lines are the controller (USD 85), the enclosure tube and floor plate (USD 30), the supervisor with its coil economizer (USD 34), the contactor (USD 25) and the connector set (USD 24).
- The contactor coil economizer (decided 2026-10-02) added USD 4 to the supervisor line.
- Making the design constructable added USD 28: the enclosure tube and floor plate (USD 8 more), the sockets with flanges and frames, the M8 speed socket and the membrane vent (USD 6), brake levers in place of bare switches (USD 6), the speed sensor's plug (USD 2), the harness branch (USD 2) and rivet nuts and fixings (USD 4).
- Savings worth trying: a stock finned extrusion close to the drawn size rather than a custom one; buying the motor, the brake levers and the pod as one e-bike kit; and, once the interface is settled, laying the supervisor out on one small circuit board in place of modules on a carrier board (TRL 4 work).

## Decisions made

| Date | Decision | Decided by | Record |
| --- | --- | --- | --- |
| 2026-09-25 | TRL 2 review items 1 to 11: budget scope (motor costed to hosts), 20 V lower bound, VESC-class controller, DC contactor, stop category 0, interface v0.1, SwapCell heartbeat, CellGuard link, 350 W heavy case, separate firmware, CargoMule as first host | Amish: "i accept all your recommendations, go with them across all repos." | MTC-DDR-001, MTC-DDR-002 |
| 2026-09-25 | R12 module mass limit relaxed from 1.5 to 2.0 kg | Amish, same instruction | MTC-DDR-002 item 15 |
| 2026-09-25 | TRL 3 engineering rules: two CAN buses, 0.6 s precharge with a 90 % bus check, DC-rated fuses with 1 kA breaking capacity, 4 mm² leads for 24 V hosts, 24 V Zener coil suppressor | Amish, same instruction | MTC-DDR-002 item 16 |
| 2026-09-25 | R1 upper bound raised from 58 to 60 V for CellGuard 16S packs (overvoltage fault 66 V, fuses 60 V DC as consequences) | Amish, same instruction | MTC-DDR-002 item 17 |
| 2026-09-25 | Evaluate a sealed power connector before interface v0.1 is frozen; XT90 provisional | Amish, same instruction | MTC-DDR-002 item 18 |
| 2026-10-01 | The budget is a value-engineering target, not a limit | Amish: "the budgets are a hypothethical control target to ensure we are thinking along a value engineering lens. its ok to ensure wording reflects that the hypothesis budget was x - the real cost being accrued is y" | `.kit/STANDARDS.md` section 18 |
| 2026-10-02 | Design for construction accepted as made: the changes P1 to P14 (finned tube on a floor plate, rivet nuts, sockets through the wall, supervisor board layout, bench rig and the others) and their knock-on changes | Amish: "i approve your recommendations for all 555 open decisions." | MTC-DDR-003, Table 1 |
| 2026-10-02 | Interface v0.2: option (a). Issue interface v0.2 with an M8 4-pin speed socket and the pin-out of build plan Table 3, and tell CargoMule, the first host, of the fifth socket | Amish: "i approve your recommendations for all 555 open decisions." | MTC-DDR-003, A1 |
| 2026-10-02 | Bench rig: option (a). Build it with the first prototype, outside the kit total (USD 35) | Amish: "i approve your recommendations for all 555 open decisions." | MTC-DDR-003, A2 |
| 2026-10-02 | Contactor coil economizer: fit it, wired so the safety loop breaks the coil supply upstream of the economizer, so a stop still drops the contactor within the 50 ms the e-stop timing assumes | Amish: "i approve your recommendations for all 555 open decisions." | MTC-DDR-002 item 19; MTC-DDR-003, A3 |
| 2026-10-02 | Sealed power connector: do the paper evaluation now against one rule (keyed, IP67 when mated, at least 40 A continuous at 60 V DC, no exposed live contacts on the pack side); first candidate class, an industrial IP67 single-pole power connector such as Amphenol's SurLok Plus. The XT90 stays for the bench prototype only | Amish: "i approve your recommendations for all 555 open decisions." | MTC-DDR-002 item 18 |
| 2026-10-02 | Dual-motor hosts (PalletPilot): two controllers on one supervisor, with one safety loop and one contactor feeding both controllers | Amish: "i approve your recommendations for all 555 open decisions." | MTC-DDR-001 item 12 |
| 2026-10-02 | Brushed motors (StepClimber): the VESC-class controller's DC motor mode; a different power stage only if StepClimber's motor needs more current than the controller is rated for | Amish: "i approve your recommendations for all 555 open decisions." | MTC-DDR-001 item 13 |
| 2026-10-02 | Appearance model: the lid window, lights, two-flange hub, layout and harness are render-only; the renders are redone on the constructable design before the repo goes public | Amish: "i approve your recommendations for all 555 open decisions." | `docs/REVIEW.md`, session of 2026-09-26 |
| 2026-10-02 | License boundary: a short written review before any firmware is published; a lawyer only if a commercial partner will ship the module | Amish: "i approve your recommendations for all 555 open decisions." | MTC-REQ-001 R13 |

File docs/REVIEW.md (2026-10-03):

# Review note: MotionCore

## Session 2026-10-01: build plan and constructable design (kit 1.7.0)

Kit 1.7.0 installed (`.kit/`, `.claude/commands/`, `CLAUDE.md`). Following `.claude/commands/build-plan.md` and `.kit/STANDARDS.md` section 18, the concept model was checked with build123d and made buildable under Amish's 2026-09-30 instruction ("fix the design assumptions to match and be physically feasible"), and the illustrated prototype build plan and the design decisions register were written. Nothing was built or tested; `trl` stays 3.

### Design changes made for construction (MTC-DDR-003, Draft, open for Amish's review)

1. Enclosure: a 56 mm cut length of finned enclosure extrusion (3 mm walls, eleven 3 x 14 mm full-height fins per side, four corner screw ports) on a separate 3 mm floor plate, joined by thermally conductive sealant and four M4 screws. The concept's extruded box with a closed floor and vertical fins cannot be extruded.
2. Lid: flat 3 mm lid on a 1 mm EPDM gasket, four M4 button-head screws with sealing washers into the corner ports (the concept lid lip clashed with the ports and had no fixing).
3. Host mounting: four M6 closed-end rivet nuts in the floor plate, rubber pads under their flanges; interface unchanged (four M6 on 180 x 100 mm).
4. Supervisor board widened to 85 x 88 mm with 35 mm standoffs beside the controller (the concept standoffs overlapped the controller by 3,300 mm³).
5. Sockets fitted straight through the 3 mm end wall at new spacings (28, 56, 83, 109 mm); the separate panel plate is dropped; XT90 stood on end in a panel frame; M12 sockets on four-screw flanges.
6. Precharge and fuse block moved beside the contactor, out of the path of the socket bodies.
7. Fixings added for the controller, contactor and fuse block (screws into holes tapped through the floor, thread sealant).
8. M8 4-pin speed sensor socket added in the side wall between two fins (the concept had no connector or free pins for the speed sensor).
9. Adhesive membrane vent on the far end wall (an M12 vent would have pushed the length past 250 mm).
10. Magnet ring bolted to the motor's six-bolt disc mount; Hall pickup on a bracket on the motor upright, 3.5 mm gap.
11. Bench rig for the prototype (new BOM line 15, USD 35, not part of the kit): plywood board, slotted motor uprights on angle feet, bar posts and a handlebar stub; the module bolts down through its own interface.
12. Brake levers with built-in normally closed switches replace bare switches (BOM line 10).
13. Harness re-routed one lead per socket (the concept ran the power socket's lead to the motor).
14. A connector pin-out for the safety loop, command and speed sockets (build plan Table 3).

`cad/src/model.py` now builds every component separately and runs 111 constructability checks (`python cad/src/model.py --check`); all pass.

### What was done

- `cad/src/model.py`: constructable model, `build_components()`, checks; STEP and STL regenerated (`cad/step/`, `cad/stl/`).
- `cad/src/sheets.py`: general arrangement MTC-DWG-001 Rev P3.
- `cad/src/concept_media.py`: concept media regenerated (concept sheet MTC-DWG-010 Rev P4, hero, exploded, cutaway, flow, `media/model.glb`).
- `cad/src/build_plan_media.py`: overview, making sketches MTC-DWG-101 to 110, two hole layouts, eight joint close-ups, sixteen assembly step pictures and the wiring diagram (`docs/05-build-plan/`, `cad/drawings/`).
- `docs/05-build-plan.md` (MTC-BLD-001 v0.1), `docs/06-design-decisions.md` (MTC-DEC-001 v0.1), `docs/decisions/0003-design-for-construction.md` (MTC-DDR-003 v0.1).
- Updated: `docs/04-calcs/sizing.py` and `01-sizing.md` (MTC-CAL-001 v0.3: floor joint, mass, cost), `docs/03-requirements.md` (v0.5), `docs/02-concept.md` (v0.5), `bom/bom.csv`, `bom/bom-notes.md`, `project.yaml` (`design_state: constructable`, new evidence), README (links line and "Building the prototype").

### Key results

- Module 240 x 168 x 69 mm, about 1.91 kg (R12 met, 0.09 kg margin).
- Thermal: walls 50.2 °C reference, 58.4 °C heavy; the new floor joint puts the floor plate at about 51.0 and **60.0 °C**, at the R9 limit. R9 stays at risk.
- Value-engineering target USD 300. Estimated cost of the constructable design USD 293 for the kit (USD 7 under the target); reference motor USD 70 to hosts; bench rig USD 35.
- Requirement status unchanged: none not met; R2, R9, R10 at risk; R11 not verifiable at TRL 3.

### Proposed, awaiting Amish

All open items are in `docs/06-design-decisions.md`: accepting MTC-DDR-003; interface v0.2 (speed socket and pin-out); the bench rig; the coil economizer (now also the remedy for the floor joint's 1.6 K); the sealed power connector; dual-motor and brushed-motor hosts; the render-only appearance differences; the firmware license review.

### Stale media (made on Amish's Mac)

`media/render-hero.png`, `media/render-exploded.png`, `media/render-detail.png`, `media/card.png` and `media/social-preview.png` still show the concept: connector panel plate, lid lip, 4 mm fins, kit loose on a bench. `cad/src/product_model.py` reads the old panel and fin parameters and needs updating to the constructable design before they are rendered again.

### Safety

The build plan carries six safety stops: no battery during the build, fuse out until checked, first power from a current-limited bench supply, e-stop and precharge checks before the motor is plugged in, wheel clear and a second person at the e-stop for every run, and a pack with its own BMS and a correctly rated fuse. The safety functions remain paper designs until TRL 4.

### Recommended next step

Amish's review of MTC-DDR-003 and the register's open decisions 1 to 4; then the sealed power connector evaluation (open decision 5). Building to the plan is TRL 4 work and stays on hold.

## Session 2026-09-25: recommendations accepted

On 2026-09-25 Amish wrote: "i accept all your recommendations, go with them across all repos." Every item with a recommendation is now **decided by Amish, 2026-09-25: go with recommendation**. The decisions are recorded in `docs/decisions/0002-recommendations-accepted.md` (MTC-DDR-002 v0.1), and MTC-DDR-001 moved to v0.2 with its statuses updated.

### Decisions applied and what changed

| Item | Decision | Before | After |
| --- | --- | --- | --- |
| MTC-DDR-001 items 1 to 11 | Decided as recommended (budget scope, input range, controller, contactor, stop category, interface v0.1, SwapCell heartbeat, CellGuard link, 350 W heavy case, separate firmware, CargoMule first) | "Adopted for TRL 3, open for Amish's review" | "Decided by Amish, 2026-09-25"; no design change |
| Budget (item 1) | Option (b): budget covers the MotionCore kit; motor costed to hosts | `budget_usd` $300 | $300, unchanged (no new figure was recommended); kit $265, $35 margin |
| R12 mass (item 15) | Option (a): relax the limit | 1.5 kg, **not met** (1.94 kg) | 2.0 kg, met with 0.06 kg margin |
| R1 upper bound (item 17) | Raise to cover CellGuard 16S LiFePO4 (58.4 V full) | 20 to 58 V | 20 to 60 V |
| Controller overvoltage fault (item 16, as a consequence of item 17) | Keep headroom above a full 16S pack | 60 V; bus peak 62.0 V | 66 V; bus peak 67.8 V (75 V rating) |
| Fuse rating (item 16, as a consequence of item 17) | Follow R1 | 58 V DC or more, 1 kA | 60 V DC or more, 1 kA |
| Direct-drive back-EMF limit | Follows the 60 V bound | 1.29 times no-load speed | 1.25 times no-load speed |
| Other TRL 3 engineering proposals (item 16) | Confirmed: two CAN buses, 0.6 s precharge with 90 % check, 4 mm² leads for 24 V, 24 V Zener suppressor | Awaiting confirmation | Decided design rules (MTC-PRC-001 v0.4 item 11) |
| R10 sealing (item 18) | Evaluate a sealed power connector before freezing interface v0.1 | XT90 in interface v0.1 | XT90 marked provisional; evaluation is a later TRL 3 paper task; geometry unchanged |

Files changed: MTC-PRB-001 v0.4, MTC-PRC-001 v0.4, MTC-REQ-001 v0.4, MTC-CAL-001 v0.2 (`docs/04-calcs/01-sizing.md`, `sizing.py`, `results.csv`), MTC-DDR-001 v0.2, new MTC-DDR-002 v0.1, `bom/bom.csv` (items 2, 5 and 8 specifications; no price change), `bom/bom-notes.md`, `cad/src/sheets.py` and MTC-DWG-001 Rev P1 to P2 (notes only), `cad/src/concept_media.py` and concept sheet MTC-DWG-010 Rev P2 to P3 (key figures), `project.yaml` (evidence list), `README.md`. `cad/src/model.py` is unchanged; STEP, STL, drawings, media and all PDFs were regenerated, and the regenerated hero, blueprint, exploded view and drawing were checked by eye.

The README "What sparked the idea" section was rewritten around a documented precedent: the 2006 CPSC recall of about 23,500 Segway personal transporters that could apply reverse torque unexpectedly, fixed by a software upgrade ([CPSC](https://www.cpsc.gov/Recalls/2006/segway-inc-announces-recall-to-repair-segway-personal-transporters)). The earlier text that attributed the idea to a review of research areas was removed. `docs/01-problem.md` did not attribute the idea to a review.

### Requirement status now (MTC-CAL-001 v0.2)

Ten of fourteen met on paper; none not met; three at risk; one not verifiable at TRL 3.

| ID | Status | Value |
| --- | --- | --- |
| R2 | At risk | Met electrically; 350 W heavy case limited by R9 |
| R9 | At risk | 50.2 °C reference; 58.5 °C heavy (65 to 71 °C in sensitivity cases) |
| R10 | At risk | XT90 not sealed; sealed connector to be evaluated; vibration not analyzed |
| R11 | Not verifiable at TRL 3 | Interface v0.1 drawn; fit time needs a timed fit (TRL 4) |
| R12 | Met | 1.94 kg against 2.0 kg (was not met against 1.5 kg) |
| R1, R4, R13 | Met (design review) | 20 to 60 V with 75 V parts; key reset; separate firmware, formal license review open |
| R3, R5, R6, R7 | Met (paper) | 67 ms; 75 ms; 0.60 to 0.70 s; 170 ms |
| R8 | Met | 0.55 A peak (0.60 A at 60 V), 1.3 A at closure, 0.6 s |
| R14 | Met (indicative) | $265 against $300 |

### Still awaiting Amish

1. **Dual-motor hosts (PalletPilot):** two controllers on one supervisor, or two modules. No recommendation.
2. **Brushed motors (StepClimber):** VESC DC mode or a different power stage. No recommendation.
3. **Contactor coil economizer** (heavy case about 55.7 °C instead of 58.5 °C): a suggestion only, not a recommendation.

### Cross-repo actions (not changed here)

- **CellGuard:** MotionCore now accepts 16S LiFePO4 up to 58.4 V (R1 20 to 60 V). CellGuard should confirm its 16S pack resistance so that MotionCore can check the prospective short-circuit current against the 1 kA fuse breaking capacity.
- **SunSpoke:** SunSpoke's host adapter is also its SwapCell charge host (mode 3); whether it keeps that adapter is for the SunSpoke project (MTC-DDR-001 item 14).
- **SwapCell:** the open question shared with PowerBox stands: may a pack in legacy discharge accept a heartbeat and move to mode 2 without opening its output?
- **CargoMule:** confirm it agrees to be the first host (MTC-DDR-001 item 11).
- **GravitySort:** update its MotionCore cost from "about $325" to $265 for the kit plus $70 for the motor.

### Safety

- The overvoltage fault at 66 V leaves less margin to the 75 V MOSFET rating (bus peak 67.8 V instead of 62.0 V). Direct-drive hosts need a speed limit below 1.25 times no-load speed or a bus clamp.
- Fuses must be rated for 60 V DC or more with 1 kA breaking capacity; 32 V automotive fuses are not suitable.
- R12's 0.06 kg margin means any added part must be weighed; do not thin the enclosure, which is the heat sink.
- All other safety concerns from the TRL 3 session below still apply.

### TRL

`trl: 3` and `trl_target: 3` are unchanged. TRL 4 (bench build, safety-function tests, timed fit, vibration) remains on hold by Amish's instruction; nothing in this session started it.

### Recommended next step

A TRL 3 paper evaluation of sealed power connectors for interface v0.1 (R10), then freeze the interface.

## Session 2026-09-25: TRL 3

### What was done

- `docs/decisions/0001-trl2-review-decisions.md` (MTC-DDR-001 v0.1): the eleven TRL 2 recommendations adopted as recommended for TRL 3 under Amish's 2026-09-25 instruction, open for his review; open items listed.
- `docs/04-calcs/01-sizing.md` (MTC-CAL-001 v0.1) with `docs/04-calcs/sizing.py` and `results.csv`: operating points, fuses, contactor and leads, thermal with sensitivities, e-stop timing, precharge, speed sensing, reaction times, CAN loads, bus voltage, size, mass and cost. The script reads `cad/src/model.py` parameters and `bom/bom.csv` and prints every quoted number.
- `cad/src/model.py`: parametric build123d model of the module (enclosure with fins and M6 mounting inserts, lid, controller, supervisor, contactor, precharge and fuse block, connector panel with the four interface v0.1 connectors, isolation pads) and the reference kit devices. Exports `cad/step/` and `cad/stl/` `motioncore-module`, `motioncore-enclosure` and `motioncore-kit`.
- `cad/src/sheets.py` and `cad/drawings/MTC-DWG-001.svg`, `.pdf`, `.png`: general arrangement of the module, Rev P1, "CONCEPT, NOT FOR FABRICATION" (the concept sheet keeps MTC-DWG-010, now at P2).
- `bom/bom.csv`: all 14 lines priced with supplier types and the TRL 3 selection criteria; `bom/bom-notes.md` totals against the budget.
- `cad/src/concept_media.py` now builds from the model; all media in `media/` regenerated and checked by eye. The module is centered on the origin, so the kit's cutaway cuts through it; the connector panel and pads are excluded from the section.
- Docs updated to v0.3 with revision entries dated 2026-09-25: MTC-PRB-001, MTC-PRC-001, MTC-REQ-001. `project.yaml`: `trl: 3`, `trl_target: 3`, evidence listed, pitch reworded. `README.md`: TRL 3, new pitch, concept numbers from MTC-CAL-001, links to the drawing and sizing note.

### Requirements (MTC-CAL-001)

Nine of fourteen met on paper; one not met; three at risk; one not verifiable at TRL 3.

| ID | Status | Value |
| --- | --- | --- |
| R12 | **Not met** | Module about 1.94 kg against 1.5 kg (size 243 x 168 x 66 mm is met) |
| R2 | At risk | Met electrically; 350 W heavy case limited by R9 |
| R9 | At risk | 50.2 °C reference; 58.5 °C at 350 W on 8S LiFePO4, 65 to 71 °C in sensitivity cases; about 68 °C at 500 W |
| R10 | At risk | XT90 power socket is not sealed; vibration not analyzed |
| R11 | Not verifiable at TRL 3 | Interface v0.1 drawn; the 2 h fit needs a timed fit |
| R1, R4, R13 | Met (design review) | 20 to 58 V with 75 V parts; key reset; separate firmware, formal license review open |
| R3, R5, R6, R7 | Met (paper) | E-stop 67 ms worst case; brake 75 ms; overspeed trip 0.60 to 0.70 s; faults 170 ms worst |
| R8 | Met | 0.55 A peak, 1.3 A at closure, ready in 0.6 s |
| R14 | Met (indicative) | MotionCore kit $265 against $300; reference motor $70 costed to hosts ($335 with motor) |

TRL 2 numbers corrected: pack power 333 to 322 W, controller loss 16 to 3.9 W, e-stop about 60 to 67 ms worst case, precharge closure 0.5 to 0.6 s (0.5 s left up to 8 A at closure on a low-resistance pack), module 1.3 to 1.94 kg, kit 4.4 to 5.3 kg, CargoMule pack 36 V class to 12S LiFePO4 at 38.4 V.

### Decisions recorded (MTC-DDR-001)

Items 1 to 11 are decided by Amish, 2026-09-25: go with recommendation (MTC-DDR-002): budget option (b) with the motor costed to hosts and `budget_usd` unchanged at $300; 20 to 58 V input; VESC-class controller; DC contactor; stop category 0 by default; interface v0.1 connectors; supervisor sends the SwapCell heartbeat; CellGuard link over CAN; heavy case derated to 350 W on 24 V; separate firmware licensing; CargoMule as proposed first host. The pitch in `project.yaml` and the README was reworded to match item 1 (DDR-001 records the wording); the problem line is unchanged.

### Still awaiting Amish

Update, 2026-09-25: items 1, 3 and 4 below are now decided by Amish, 2026-09-25: go with recommendation (MTC-DDR-002); item 5 is settled by item 1 of MTC-DDR-001 ($300 unchanged); item 2 stays proposed, awaiting Amish.

1. **R12 mass (new at TRL 3).** Options: (a) relax R12 to 2.0 kg; (b) 2 mm walls and lid with 3 mm fins, about 1.63 kg, still over and with less heat-sink metal; (c) (b) plus a lighter contactor. Recommendation: (a), because the enclosure is the heat sink and R9 is already at risk.
2. **Dual-motor hosts (PalletPilot)** and **brushed motors (StepClimber)**. No recommendation was made; they stay proposed, awaiting Amish.
3. **R10 sealing.** Options: a sealing boot over the XT90, or a sealed power connector in interface v0.1. Recommendation: evaluate a sealed connector before freezing the interface; this changes an adopted interface item, so it needs Amish.
4. **Engineering proposals from MTC-CAL-001** (DDR-001 item 16): two CAN buses on the supervisor, precharge closure at 0.6 s with a 90 % bus check, 58 V DC fuses with 1 kA breaking capacity, 4 mm² pack leads for 24 V hosts, 24 V Zener coil suppressor, controller overvoltage fault at 60 V. A coil economizer (heavy case about 56 °C instead of 58.5 °C) is a suggestion only, not in the BOM.
5. **Budget.** No new figure was recommended; `budget_usd` stays $300 for the MotionCore kit. A complete kit with motor is $335 for host budgets.

### Cross-repo notes (not changed in other repos)

- **SwapCell:** MotionCore builds to interface v0.3 as a vehicle host (type 0, mode 2; mode 4 only when a host enables regeneration). It shares PowerBox's open question: may a pack in legacy discharge accept a heartbeat and move to mode 2 without opening its output? The supervisor is powered from the pack, so it depends on this. The INTERLOCK coding resistor is in the host's receptacle, not in MotionCore.
- **CellGuard:** consistent with CellGuard's recommendations to adopt the SwapCell message set and a STM32G0B1-class controller. Conflict: CellGuard supports 16S LiFePO4 at up to 58.4 V, just above MotionCore's 58 V limit in R1. Raising R1's upper bound to 60 V would cover it (the 75 V parts allow it); decided by Amish, 2026-09-25: go with recommendation (MTC-DDR-002).
- **SunSpoke:** its host adapter is also the SwapCell charge host (mode 3), so the MotionCore heartbeat does not let SunSpoke drop the adapter unless SunSpoke keeps a charge host elsewhere.
- **CargoMule:** its 15 A pack limit caps its peak at about 414 W of shaft power; that is a host setting.
- **GravitySort:** cites MotionCore at "about $325" including the motor; under item 1 that becomes $265 for the kit plus $70 for the motor.

### Safety concerns

- Every safety function (e-stop timing, restart inhibit, brake interlock, overspeed trip) is a paper claim until tested; first power-up only on a bench, wheel off the ground, second person at the e-stop. Testing is TRL 4 and on hold.
- Prospective short-circuit currents of about 470 to 860 A: the main fuse must be rated for 58 V DC or more with 1 kA breaking capacity; common 32 V automotive fuses are not suitable.
- The contactor must break DC under load at up to 58 V and release within 50 ms with a Zener suppressor; a plain diode lengthens the release.
- Regeneration with the contactor open drives the bus up at about 10 V/ms; the controller's 60 V overvoltage fault is part of the safety case. Direct-drive hosts need a speed limit below 1.29 times no-load speed or a bus clamp.
- The heavy case runs within 1.5 K of the 60 °C case limit in shade and above it in sun.
- A category 0 stop does not brake; hosts need unpowered brakes. Bridging the safety loop defeats every protection. A wrong wheel circumference moves the speed limit.
- MotionCore is not certified and does not make a host compliant with any machinery, vehicle or pedelec rule.

### Other notes

- No TRL 4 material exists in the repo; `build-log/README.md` is the scaffold stub and was not touched.
- Citations: the TRL 2 note lists no unchecked citations, so none were fetched.
- `render.py --check` and `render.py` pass; PDFs are in `docs/pdf/`.

### Recommended next step

Review MTC-DDR-001 and the items above, in particular R12 (mass) and the R1 upper bound for CellGuard's 16S packs. TRL 4 is on hold by Amish's instruction. For reference only, TRL 4 would need: a bench build of the module, a lab test report (TST, `environment: lab`) covering e-stop power-removal time, restart inhibit, brake interlock, overspeed trip, precharge inrush and case temperature at 250 W and 350 W, a timed fit on one host, and build-log entries. None of this has been started.

## Session 2026-09-25: /populate to a strong TRL 2

### What was done

- `docs/01-problem.md` (MTC-PRB-001 v0.2): problem with cited figures, users, host project table (SunSpoke, CargoMule, PalletPilot, StepClimber, DustRunner), operating environment, constraints, out of scope, prior work with links (VESC, ODrive, SimpleFOC, ISO 13850, IEC 60204-1, ISO 13849-1, Regulation (EU) No 168/2013), open questions and a new co-design checklist aimed at the host project leads.
- `docs/03-requirements.md` (MTC-REQ-001 v0.2): 14 measurable requirements (R1 to R14) with targets, verification method and a status column against the TRL 2 estimates; reference and heavy cases defined; assumptions listed.
- `docs/02-concept.md` (MTC-PRC-001 v0.2): how it works (power up, enable, drive, watch, stop), numbered components, draft connector interface v0.1, first-order numbers (currents and fuse, e-stop timing, precharge, thermal, speed sensing, size, mass and cost), proposed design choices, safety section, open questions.
- `cad/src/concept_media.py`: massing model of the reference kit on a bench (module with fins, controller, supervisor, contactor, precharge and fuse block, lid, connector panel, 250 W hub motor, e-stop station, brake switches, key and throttle pod, speed sensor, harness), each part with a BOM number; bench top and a phone as the scale context instead of the 1.75 m figure, because the kit is bench-sized.
- `media/`: `hero.png`, `concept-blueprint.png`, `.pdf` and `.svg`, `exploded.png` (callouts 1 to 13 match the BOM), `cutaway.png` (inside of the module), `flow.png` (power flow at 250 W, all values estimates), `model.glb` and `viewer.html`.
- `bom/bom.csv`: 14 lines with indicative prices, numbered to match the exploded view; `bom/bom-notes.md` updated.
- `README.md`: hero image and links line; Concept rationale, Burning platform, By industry, By country or region and What sparked the idea expanded with cited figures; Concept, Key components and Safety updated to match.
- `docs/pdf/`: branded PDFs of the three controlled documents.

### Key results (estimates, to be checked at TRL 3)

| Quantity | Estimate | Requirement |
| --- | --- | --- |
| Input range | 20 to 58 V DC (24, 36, 48 V hosts incl. SwapCell) | R1 met by design |
| Pack current, reference case (250 W shaft, 46.8 V) | about 333 W, about 7.1 A | Fuse 20 A |
| Pack current, heavy case (500 W, 25.6 V) | about 26 A | Fuse 40 A |
| E-stop power removal | about 60 ms (contactor drop-out 20 to 50 ms, assumed) | R3 met on paper (100 ms) |
| Travel during 100 ms | about 0.7 m at 25 km/h; about 0.15 m at 1.5 m/s | |
| Precharge | about 0.55 A peak, 0.5 s, 1.5 J per start | R8 met |
| Case temperature at 40 °C ambient | about 55 °C at 250 W; about 67 °C at 500 W | R9 met at 250 W; **not met at 500 W** |
| Module size and mass | about 250 x 170 x 66 mm, about 1.3 kg; kit about 4.4 kg | R12 met |
| Reference kit cost | about $325 (module and devices about $255, motor about $70) | **R14 not met, about 8 % over $300** |

Requirements not met or at risk:

- **R14 (cost) not met:** about $325 against $300.
- **R9 (thermal) not met in the heavy case:** about 67 °C case against 60 °C at 500 W on 24 V; R2 at 500 W is therefore at risk.
- **R13 (open licensing) at risk:** VESC firmware is GPL-3.0; the boundary with the MIT supervisor firmware needs review.
- **R10 (ingress and vibration)** not yet assessed.
- **R3 to R7** (e-stop, restart inhibit, brake interlock, speed limit, fault reaction) are met on paper only; none is verified.
- DustRunner (12.8 V) is outside the proposed input range, so MotionCore does not cover all five host projects.

### Proposed, awaiting Amish

Update, 2026-09-25: all eleven items below are decided by Amish, 2026-09-25: go with recommendation (MTC-DDR-001 v0.2, MTC-DDR-002).

1. **Budget.** Options: (a) raise `budget_usd` from $300 to $330; (b) cost the motor to each host, so the MotionCore kit (module and devices, about $255) meets $300, which changes the pitch wording ("motor, controller and safety module"); (c) cut cost (cheaper VESC variant, local enclosure) to reach $300. Recommendation: (b), keeping the motor as a named reference part in the interface. `project.yaml` is unchanged.
2. **Input range.** 20 to 58 V (recommended) versus adding a 12 V variant to cover DustRunner.
3. **Controller.** VESC class (recommended) versus ODrive or a custom stage with Safe Torque Off.
4. **Power-removal element.** DC contactor (recommended at TRL 2) versus gate-driver Safe Torque Off.
5. **Stop category.** Category 0 default (recommended) with category 1 as an option for heavier hosts, versus category 1 by default.
6. **Interface v0.1 connectors.** XT90 anti-spark, 9-pin motor plug, two keyed M12 connectors (recommended), versus all-automotive sealed connectors.
7. **SwapCell host role.** Let the supervisor send the SwapCell heartbeat (recommended; would let SunSpoke drop its separate host adapter, subject to that project's agreement) versus leaving it to each host. This needs no change to the SwapCell interface.
8. **CellGuard link.** Supervisor reads CellGuard BMS faults over CAN and removes torque (recommended).
9. **Heavy-case thermal fix.** Derate to 350 W continuous at 24 V (recommended at TRL 2), versus a fan, versus mounting to the host frame.
10. **Firmware licensing.** Keep VESC firmware unmodified as a separate program and the supervisor under MIT (recommended, pending review), versus licensing the supervisor firmware under GPL-3.0.
11. **First host.** SunSpoke or CargoMule (250 W geared hub, closest to the reference case) as the first adopter; recommendation: CargoMule, which also needs the brake interlock for its overrun coupler.

### Safety concerns

- The safety functions are unverified; first power-ups must be on a bench with the wheel off the ground and a second person at the e-stop.
- A category 0 stop does not brake; hosts must have brakes that work unpowered, and walk-behind hosts need spring-applied brakes.
- Direct-drive motors can pump the bus voltage through the MOSFET body diodes when pushed with the contactor open; a bus clamp is needed for those hosts.
- Contactor arcing when breaking DC under load at up to 58 V; part must be DC-rated at full pack voltage.
- Pack short-circuit current, residual charge in bus capacitors, and a hot enclosure (about 55 to 67 °C).
- Bridging the safety loop defeats every protection; keying and plain fault documentation are the only defense at this level.
- MotionCore is not certified and does not make a host compliant with any machinery, vehicle or pedelec rule.

### Problems and notes

- The kit is bench-sized, so the hero uses a bench top and a phone for scale rather than the 1.75 m figure.
- The cutaway shows the module interior only; external devices are excluded from the section.
- The legacy `cad/src/model.py` placeholder is untouched (TRL 3 work).
- Host README figures in Table 1 of MTC-PRB-001 are taken from the host repos as they stand; if a host changes voltage or motor, the table needs an update.

### Recommended next step

Review this note and the media, then decide items 1, 2 and 7. If approved, run `/advance-trl3` to check the e-stop timing, precharge, thermal and fuse estimates by calculation, choose the contactor and controller parts, freeze interface v0.1 and produce the parametric model and drawing sheet.

## Session 2026-09-26: sources strengthened

| README item | Old source | New source |
| --- | --- | --- |
| Kenya row (By country or region) | CleanTechnica, 2025, reporting KNBS 2024 registrations (trade press, standing alone) | [IEA Global EV Outlook 2026, trends in other EV modes](https://www.iea.org/reports/global-ev-outlook-2026/trends-in-other-ev-modes): electric two-wheeler sales more than tripled in 2025 to over 25,000, around 15 % of new registrations |

All other links in the four sourced README sections (IEA, CPSC micromobility report, HSE fatal injury statistics, Regulation (EU) No 168/2013, CPSC 2006 Segway recall) were fetched and confirmed on 2026-09-26. `docs/01-problem.md` did not cite the replaced source, so no controlled document changed.

## Session 2026-09-26: product appearance model and photoreal renders

Amish chose this repo for the first batch of product renders on 2026-09-26. This session added `cad/src/product_model.py`, an appearance model for photoreal renders, and pointed the README hero at `media/render-hero.png` with a link to `media/render-exploded.png`. The render files are produced separately by the portfolio render pipeline.

### What `product_model.py` adds

- `product_parts()`: 76 parts (27 shell, 19 internal, 26 accessory, 4 context), each with a colour, a render material, its BOM line and an explode offset; `TITLE` and three `RENDER_VIEWS` (hero, exploded, and a module-only detail view).
- Enclosure: rounded extrusion corners, finned sides with rounded fin tips, a gasket parting line under the lid, six stainless lid screws, a teal name plate and a rating label.
- Connector panel: yellow XT90 anti-spark socket with contacts, knurled 9-pin motor socket, two threaded M12 sockets with yellow (safety loop) and teal (command) coding rings, vent plug, panel screws and legends.
- Internals behind the window: controller heat plate, board, bus capacitors and phase terminals; supervisor board on brass standoffs with MCU, CAN transceivers, USB fault-log port and a lit heartbeat LED; contactor with terminal studs and label; aluminum-clad precharge resistor, fuse holder and blade fuse.
- Reference hub motor with two spoke flanges, side covers and screws, axle flats, nuts and washers; speed sensor magnet ring with eight magnets and the Hall pickup on a small bracket.
- E-stop station with rounded yellow enclosure, lid seam and screws, legend disc, collar, red mushroom head and cable gland; key and throttle pod with key, legend ring and ribbed thumb lever; the pair of brake switches with levers and plungers.
- Context: a compact bench top and a simplified harness with mated plugs and a pack lead.

### Differences from `model.py` (Proposed, awaiting Amish)

1. **Clear inspection window in the lid** (175 x 84 mm polycarbonate pane over the supervisor, contactor and fuse block). The BOM lists a plain 3 mm aluminum lid. Recommendation: keep the window for renders only and leave the BOM lid unchanged; if Amish wants it as a feature, assess sealing (R10) and the lid's heat-sink role first.
2. **Ready and fault lights on the connector panel** (green lit, red unlit). Not in the BOM or interface v0.1. Recommendation: accept as a render detail and, if wanted, add two light pipes from the supervisor board at the next design step.
3. **Hub motor with two spoke flanges** instead of the single central flange in `model.py`, same flange radius (motor radius plus 6 mm). Recommendation: accept; it matches a real geared hub and changes no interface.
4. **Render layout.** Motor axle at X = -300 mm (model.py: -380 mm) and raised 6 mm so its flanges rest on the bench; e-stop station at (255, 60) mm (model.py: 300, 150); key and throttle pod and brake switches moved closer to the module. Recommendation: accept as a render-only layout; `model.py`, the STEP files and MTC-DWG-001 keep the bench layout.
5. **Harness** simplified to one lead per device with mated plugs and an XT90 pack plug, routed for the render layout; brake and speed sensor leads merge into the motor lead run. Recommendation: accept as a render-only simplification.

### Status

This is an appearance model only: no tolerances, no fabrication detail, and every main dimension and interface comes from `PARAMS` in `model.py`, which is unchanged, as are the BOM and the docs. `trl` stays 3, and TRL 4 remains on hold.

## Session 2026-09-27: kit 1.5.0 and image quality

- Kit 1.5.0 synced: STANDARDS v1.5 (sections 12 to 15: product renders, storefront images and image quality, public release, authorship and signing), `.kit/cards.py`, `.kit/image_qc.py`, `.kit/release_gate.py`, issue templates, and the `/render-product` and `/release` commands. `CLAUDE.md` now matches `.kit/CLAUDE.md`.
- Every `media/render-*.png` recaptioned from its original render with the new layout: the title, concept label and repository sit in a band above the render and the view note in a band below it, each line wrapped to the image width, so no text overlaps other text or the render or runs off the image. `media/card.png` and `media/social-preview.png` regenerated with the same rules.
- `python .kit/image_qc.py` and `python .kit/release_gate.py` pass. trl stays 3.

## Session 2026-10-02: open decisions decided

Amish, 2026-10-02: "i approve your recommendations for all 555 open decisions." This approves the recommendation written for every open decision in the design decisions register (MTC-DEC-001). trl stays 3; nothing was built, bought or tested, and TRL 4 remains on hold.

### Decisions recorded (9)

| Register item | Decision |
| --- | --- |
| 1 | MTC-DDR-003 accepted as made: P1 to P14 and their knock-on changes |
| 2 | Interface v0.2 issued with the M8 4-pin speed socket and the build plan Table 3 pin-out; CargoMule told of the fifth socket |
| 3 | Bench rig built with the first prototype, outside the kit total |
| 4 | Coil economizer fitted, wired so the safety loop breaks the coil supply upstream of it (stop within 50 ms) |
| 5 | Sealed connector paper evaluation now: keyed, IP67 mated, 40 A or more at 60 V DC, no exposed live contacts; first candidate class such as Amphenol SurLok Plus; XT90 for the bench prototype only |
| 6 | Dual-motor hosts: two controllers on one supervisor, one safety loop and one contactor feeding both |
| 7 | Brushed motors: VESC DC motor mode, unless StepClimber's motor needs more current |
| 8 | Lid window, lights, two-flange hub, layout and harness render-only; renders redone on the constructable design before going public |
| 9 | Short written license boundary review before any firmware is published; lawyer only for a commercial partner |

All 9 moved to Decisions made in MTC-DEC-001, dated 2026-10-02; the Open decisions section now reads "None."

### Documents changed

- `docs/06-design-decisions.md` (MTC-DEC-001 v0.2): items 1 to 9 moved to Decisions made; Open decisions reads "None"
- `docs/decisions/0003-design-for-construction.md` (MTC-DDR-003 v0.2): status accepted (kept Draft); A1 to A3 marked accepted; consequence for the economizer added
- `docs/decisions/0001-trl2-review-decisions.md` (MTC-DDR-001 v0.3): items 12 and 13, marked "Proposed, awaiting Amish", recorded as decided
- `docs/decisions/0002-recommendations-accepted.md` (MTC-DDR-002 v0.2): items 12, 13 and 19, marked as awaiting Amish, recorded as decided
- `docs/03-requirements.md` (MTC-REQ-001 v0.6): R9, R10, R11 and R13 status notes for the decisions; no status changed
- `docs/04-calcs/01-sizing.md` (MTC-CAL-001 v0.4): economizer, connector, interface v0.2 and license review noted; figures unchanged
- `docs/02-concept.md` (MTC-PRC-001 v0.6): connector table caption (interface v0.2, XT90 bench only); economizer; open questions answered
- `docs/01-problem.md` (MTC-PRB-001 v0.5): brushed and dual-motor host questions answered
- `docs/05-build-plan.md` (MTC-BLD-001 v0.2): section 2 says MTC-DDR-003 is accepted
- `bom/bom-notes.md`: economizer, XT90 bench-only and interface v0.2 noted, not yet in BOM lines or prices
- PDFs regenerated with `python3 .kit/render.py`; superseded versions removed.

### Follow-up actions to carry approved decisions into the design

The model, BOM quantities and prices, calculations and pictures were not changed in this session. These actions carry the approved decisions into them:

1. Decision 4 (model, BOM, calculations): Add the contactor coil economizer: BOM line and price, its place on the supervisor carrier board in the model, and the heavy-case thermal result in `docs/04-calcs/sizing.py` (about 55.6 °C walls, 57 °C floor plate) so R9 can be re-rated.
2. Decision 4 (build plan pictures, drawings): Redraw the supervisor and safety loop wiring so the loop breaks the coil supply upstream of the economizer, and check the 50 ms contactor drop-out in the e-stop timing.
3. Decision 2 (documents): Issue interface v0.2 (four v0.1 sockets plus the M8 speed socket, build plan Table 3 pin-out) and tell CargoMule of the fifth socket.
4. Decision 5 (documents, then model and BOM): Write the sealed power connector paper evaluation (IP67 mated, 40 A or more at 60 V DC, keyed, no exposed live contacts); once a connector is chosen, change the end wall hole, the socket frame and BOM line 8.
5. Decision 6 and 7 (documents): Record the dual-motor and brushed-motor host arrangements in the interface notes for PalletPilot and StepClimber (cross-repo).
6. Decision 8 (pictures): Redo the photoreal renders, card and social preview on the constructable design on Amish's Mac before the repo goes public; keep the lid window out of the design.
7. Decision 9 (documents): Write the license boundary review before any firmware is published.

### Points found in the review

Raised when the recommendations were written (2026-10-01) and kept here so they are not lost:

- The 2026-09-26 recommendation for the lid window said to assess sealing (R10) and the lid's heat-sink role first; the register's item 8 drops that caveat.
- The sealed connector evaluation (item 5) was decided as a paper task on 2026-09-25 (MTC-DDR-002, item 18) and is TRL 3 work, but it has not been done, so interface v0.2 (item 2) is being frozen with a provisional power connector.
- MTC-DDR-002 notes that the CellGuard 16S pack's prospective short-circuit current is unknown against the fuse's 1 kA breaking capacity; this safety check sits only in 'To confirm when parts are bought', where it could be missed before a CellGuard host is fitted.
- The SwapCell legacy-discharge heartbeat question is shared with PowerBox (its item 8); it should be tracked once, as one cross-repo action with SwapCell.

## Session 2026-10-02: approved follow-ups carried out

Amish approved all follow-up actions from the open-decision sign-off on 2026-10-02. trl stays 3; nothing was built or tested.

### Approved follow-ups carried out

1. Decision 4 (model): done. Contactor coil economizer module added on the supervisor carrier board in `cad/src/model.py` (board 85 x 108 mm, module 24 x 14 x 8 mm, six new clearance checks; 116 of 116 constructability checks pass); BOM line 3 now USD 34 (was USD 30, USD 4 for the module, indicative); `docs/04-calcs/sizing.py` now takes the held-coil heat from the economizer: heavy case 16.5 W, 55.6 C on the walls, 56.9 C on the floor plate (was 58.4 C and 60.0 C). R9 re-rated to met on paper; R2 follows it.
2. Decision 4 (pictures): done. The wiring picture now shows the loop break upstream of a coil economizer block; the supervisor carrier board sketch (MTC-DWG-103, Rev P2) and step and joint pictures were regenerated. The e-stop timing now includes the economizer's output capacitor (limited to 100 uF): worst case 74 ms (was 67 ms), modeled 37 ms; the contactor must still release within 50 ms; inside the 100 ms of R3.
3. Decision 2 (docs): done. Interface v0.2 is issued in the precis (`docs/02-concept.md`, MTC-PRC-001 v0.7): four v0.1 sockets plus the M8 speed socket, with the pin-out of build plan Table 3 in Table 2a. Telling CargoMule of the fifth socket is a cross-repo action (below).
4. Decision 5 (docs): done as an evaluation: `docs/decisions/0004-sealed-power-connector-evaluation.md` (MTC-DDR-004, new, proposed) recommends an industrial IP67 single-pole pair against the rule. Not done: changing the end wall hole, socket frame and BOM line 8, because no named part is chosen at TRL 3 (the datasheet check is item 9 of "To confirm when parts are bought"). R10 stays at risk.
5. Decision 6 and 7 (docs): done in this repo: dual-motor and brushed-motor host arrangements are recorded in the precis interface section; the notes in the PalletPilot and StepClimber repos are cross-repo actions (below).
6. Decision 8 (pictures): done for the appearance model: `cad/src/product_model.py` now follows the constructable design (floor plate joint, rivet nuts, sockets through the wall with flanges and no panel plate, M8 speed socket, wall vent, fuse block and contactor foot at their model positions, lid screws, lengthened supervisor board with its economizer). The lid window stays out of the design and is render-only (it is widened to show the economizer). Photoreal renders, `media/card.png` and `media/social-preview.png` are made on the Mac: not done here.
7. Decision 9 (docs): done: `docs/decisions/0005-license-boundary-review.md` (MTC-DDR-005, new, proposed). No change of licenses; a firmware readme stating the boundary is needed before any firmware is published (TRL 4 work).

### Requirement status changes

R2: at risk to met on paper. R9: at risk to met on paper (47.0 C reference, 55.6 C heavy on the walls, 56.9 C on the floor plate, in shade; the two controller sensitivity cases still reach 62 to 68 C). R3 now 74 ms worst case (was 67 ms), still met. R10 stays at risk, R11 not verifiable. Counts: twelve met, one at risk, one not verifiable, none not met.

### Cost and mass

Value-engineering target: USD 300. Estimated cost of the constructable design: USD 297 for the MotionCore kit (USD 3 under the target); `budget_usd` unchanged. Module mass 1.92 kg (R12 limit 2.0 kg, margin 0.08 kg); kit 5.3 kg with the reference motor.

### Documents changed

`docs/04-calcs/01-sizing.md` (MTC-CAL-001 v0.5), `docs/02-concept.md` (MTC-PRC-001 v0.7), `docs/03-requirements.md` (MTC-REQ-001 v0.7), `docs/05-build-plan.md` (MTC-BLD-001 v0.3), `docs/06-design-decisions.md` (MTC-DEC-001 v0.3), `docs/decisions/0003-design-for-construction.md` (MTC-DDR-003 v0.3), new `docs/decisions/0004-sealed-power-connector-evaluation.md` and `0005-license-boundary-review.md` (v0.1), `README.md`, `bom/bom.csv`, `bom/bom-notes.md`. Drawing MTC-DWG-001 is Rev P4; MTC-DWG-103 is Rev P2. STEP and STL regenerated; concept media regenerated.

### Render scenes

Exported to `/home/claude/renders/motioncore`: hero, exploded and detail (one .npz and .json each, plus `motioncore__jobs.json`).

### Cross-repo actions

- CargoMule: tell it of the fifth socket (M8 speed, interface v0.2).
- PalletPilot: record the dual-motor arrangement (two controllers on one supervisor, one safety loop, one contactor feeding both).
- StepClimber: record the brushed-motor arrangement (the controller's DC motor mode; another power stage only if the motor needs more current than the controller is rated for).
- Any repo citing MotionCore interface v0.1 should cite v0.2.

## 2026-10-02: photoreal renders redone on the constructable design

Rendered with Blender Cycles on Amish's Mac from the updated appearance model; captioned with `.kit/photo_caption.py`; `media/card.png` and `media/social-preview.png` regenerated with `.kit/cards.py`. Views: hero, exploded, detail. image_qc passes. Appearance deviations are those logged above as proposed, awaiting Amish.

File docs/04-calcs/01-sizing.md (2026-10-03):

---
doc_id: MTC-CAL-001
title: MotionCore sizing calculations
project: MotionCore
doc_type: Calculation note
version: "0.5"
status: Draft
date: '2026-10-02'
author: Amish Chadha
license: CERN-OHL-S-2.0
revisions:
- version: "0.1"
  date: '2026-09-25'
  author: Amish Chadha
  change: First TRL 3 sizing note (currents, fuses and leads, thermal, e-stop timing, precharge, speed sensing, reaction times, CAN and bus voltage, size, mass, cost) against the TRL 3 decisions in MTC-DDR-001
- version: "0.2"
  date: '2026-09-25'
  author: Amish Chadha
  change: Recommendations accepted by Amish (DDR-002). R1 upper bound 58 to 60 V (CellGuard 16S), controller overvoltage fault 60 to 66 V, fuse rating 60 V DC or more, R12 mass limit 1.5 to 2.0 kg
- version: "0.3"
  date: '2026-10-01'
  author: Amish Chadha
  change: Constructable design (MTC-DDR-003). Finned tube on a floor plate with a sealant joint (new floor joint estimate), 3 mm full-height fins, envelope, mass and cost updated; budget reported as a value-engineering target
- version: "0.4"
  date: '2026-10-02'
  author: Amish Chadha
  change: "Decisions of 2026-10-02 noted under R9, R10, R11 and R13; figures unchanged until sizing.py includes the economizer"
- version: "0.5"
  date: '2026-10-02'
  author: Amish Chadha
  change: 'Coil economizer added (BOM line 3, carrier board, thermal and e-stop timing); R9 and R2 re-rated to met on paper; US-style kit cost USD 297'
---

# MotionCore sizing calculations

On paper, MotionCore meets twelve of its fourteen requirements and none is outright not met. R12 is met after Amish relaxed the mass limit from 1.5 kg to 2.0 kg (MTC-DDR-002): the constructable design of MTC-DDR-003 weighs about 1.92 kg, a margin of 0.08 kg, because the finned enclosure that is also the heat sink weighs about 1.0 kg on its own. R1 now runs to 60 V so that CellGuard's 16S LiFePO4 packs (58.4 V full) are covered. R2 and R9 are now **met on paper** in the heavy case, because the contactor coil economizer decided on 2026-10-02 is in the design: at 350 W on an 8S LiFePO4 pack the walls reach about 55.6 °C and the floor plate about 56.9 °C against 60 °C (they were 58.4 °C and 60.0 °C with the coil at full power), though reasonable changes to the controller assumptions still push the case to 62 to 68 °C. R10 is **at risk** because the XT90 power socket is not sealed, and R11 (fit time) cannot be verified at TRL 3. The reference case is comfortable: about 47 °C on the case, 6.9 A from a SwapCell pack, e-stop power removal within 74 ms worst case, and an estimated MotionCore kit cost of USD 297 against a value-engineering target of USD 300 (USD 3 under), with the USD 70 reference motor costed to each host.

Every number here is printed by `docs/04-calcs/sizing.py` (run from the repo root: `python docs/04-calcs/sizing.py`), which also writes `docs/04-calcs/results.csv`. The script reads the enclosure dimensions from `cad/src/model.py` and the costs from `bom/bom.csv`. All values are first-principles estimates; nothing is measured.

## 1. Assumptions

*Table 1. Inputs. All are assumptions for a paper design; part-specific values are to be confirmed from datasheets once parts are chosen.*

| Input | Value | Basis |
| --- | --- | --- |
| Reference pack | SwapCell 13S lithium-ion, 46.8 V nominal, 39.0 to 54.6 V, 110 mΩ, 20 A continuous, 35 A for 10 s | SwapCell interface v0.3 (SWC-PRC-001 v0.3) |
| CargoMule pack | 12S LiFePO4, 38.4 V nominal, 30.0 to 43.8 V, about 60 mΩ, 15 A host limit | CargoMule precis (CGM-PRC-001); resistance assumed |
| Heavy-case pack | 8S LiFePO4, 25.6 V nominal, 20.0 to 29.2 V, about 30 mΩ | PalletPilot and StepClimber class; resistance assumed |
| Motor efficiency | 80 % at rated load, 75 % at 750 W for 10 s | Typical small geared hub |
| Phase to bus current ratio | 1.2 (winding matched to the host's speed) | Assumption; 2.0 checked as a sensitivity |
| Controller losses | 3.9 mΩ per phase (MOSFET 2.4 mΩ hot, shunt 0.5 mΩ, copper 1.0 mΩ); 100 ns switching edges at 30 kHz; 1.5 W fixed | Typical VESC-class 75 V stage |
| Power path in the module | Contactor 0.5 mΩ, internal leads 1.5 mΩ, XT90 pair 0.6 mΩ, fuse 3.5 mΩ (20 A) or 1.5 mΩ (40 A) | Typical parts |
| Auxiliary supply | Coil 4.0 W at 12 V, supervisor 0.6 W, buck efficiency 85 % | Typical sealed 100 A contactor without economizer |
| Enclosure | 220 x 140 mm finned tube 56 mm tall on a 3 mm floor plate (59 mm body), 3 mm walls, 3 mm lid, 22 fins 3 x 14 x 56 mm; clear anodized, ε 0.80, solar absorptance 0.35 | `cad/src/model.py` (MTC-DDR-003) |
| Floor joint | Thermally conductive silicone sealant, 1.0 W/m·K, 0.2 mm film over 2,380 mm² of wall and port end faces | Assumed; to confirm with the chosen sealant |
| Convection | Vertical plates h = 1.42 (ΔT/L)^0.25, lid h = 1.32 (ΔT/L)^0.25, fin faces 0.8 of a free plate; underside ignored | Simplified laminar correlations for still air |
| CellGuard pack | 16S LiFePO4, 58.4 V full | R1 check only; pack resistance not known here |
| Contactor coil | 36 Ω, 0.30 H, releases at 10 % of rated current; 10 ms armature travel; 5 ms arc | Assumed; release time 50 ms or less is a selection criterion |
| Bus capacitance | 1,000 µF; precharge 100 Ω | To confirm from the chosen controller |
| Speed sensor | 8 magnets; 2 % period jitter from magnet placement | Concept (MTC-PRC-001) |
| Ambient | 40 °C, shaded | MTC-REQ-001 R9 |

## 2. Operating points (R1, R2)

The controller is more efficient than the blanket 95 % assumed at TRL 2, so the pack supplies about 322 W, not 333 W, in the reference case. At the reference point about 5.7 W goes to the auxiliary supply and power path, 3.9 W to the controller and 62.5 W to motor and gear losses (Figure 4 in MTC-PRC-001).

*Table 2. Operating points. Currents at nominal and minimum pack voltage.*

| Case | Pack power | Current, nominal V | Current, minimum V | Controller loss | Controller efficiency |
| --- | --- | --- | --- | --- | --- |
| Reference: 250 W, SwapCell | 322 W | 6.9 A at 46.8 V | 8.3 A at 39.0 V | 3.9 W | 98.8 % |
| CargoMule: 250 W, 12S LFP | 323 W | 8.4 A at 38.4 V | 10.8 A at 30.0 V | 4.3 W | 98.7 % |
| Heavy: 350 W, 8S LFP | 453 W | 17.7 A at 25.6 V | 22.9 A at 20.0 V | 9.0 W | 98.0 % |
| 500 W, 8S LFP (information) | 648 W | 25.3 A at 25.6 V | 32.9 A at 20.0 V | 15.5 W | 97.6 % |

For 750 W over 10 s at nominal voltage, the pack current is 21.9 A on SwapCell (inside its 35 A, 10 s limit) and 40.9 A on 8S LiFePO4. CargoMule's own 15 A pack limit caps its peak at about 414 W of shaft power: this is a host setting, which the supervisor respects, not a MotionCore limit. The supervisor sets the controller's battery current limit to the lower of the host setting and the pack's allowed discharge current in PACK_LIMITS.

All three host packs fall inside 20 to 60 V, and so does a full CellGuard 16S LiFePO4 pack at 58.4 V, 1.6 V below the new upper bound (MTC-DDR-002; it was 58 V). The controller is a 75 V class and the auxiliary buck accepts 18 to 75 V, so **R1 is met by design review**. R2 is met electrically, and its heavy case now holds with R9, so **R2 is met on paper**.

## 3. Fuses, contactor and leads

The fuse must carry 1.25 times the continuous current at minimum pack voltage and hold the 10 s peak at no more than 110 % of its rating, which a blade fuse carries without opening.

*Table 3. Fuse check.*

| Pack | Continuous at minimum V | 10 s peak | Fuse needed | Fitted | Prospective short circuit |
| --- | --- | --- | --- | --- | --- |
| SwapCell | 8.3 A | 21.9 A | 19.9 A | 20 A | about 470 A |
| CargoMule | 10.8 A | 15.0 A (host limit) | 13.6 A | 20 A | about 663 A |
| 8S LiFePO4 | 22.9 A | 40.9 A | 37.2 A | 40 A | about 856 A |

The 20 A and 40 A fuses proposed at TRL 2 hold, although the 20 A fuse has little margin for a SwapCell host that uses the full 750 W peak. The fuse must be rated for **60 V DC or more** (58 V before R1 was raised) with at least **1 kA** breaking capacity; common 32 V automotive fuses are not suitable. The prospective short-circuit current of a CellGuard 16S pack is not calculated here because its resistance is not known in this repo; it must be checked against the 1 kA breaking capacity before a CellGuard host is fitted. The contactor carries at most about 41 A for 10 s against its 100 A rating; the selection criterion that matters is breaking at least 50 A at 60 V DC.

Pack leads of 2.5 mm² over 1.5 m each way drop 0.14 V and lose 1.0 W in the reference case. In the heavy case at 20 V they drop 0.47 V and lose 10.8 W (3.1 % of shaft power); 4 mm² leads cut this to 0.30 V and 6.7 W, so 24 V hosts get 4 mm² pack leads (`bom/bom.csv` item 13).

## 4. Thermal (R9)

The enclosure has 0.0308 m² of lid, 0.0446 m² of walls and 0.0382 m² of fin faces (0.0454 and 0.0338 m² before MTC-DDR-003: the fins now run the full tube height). At the heavy point the heat-transfer coefficients are about 6.5 W/m²K on the walls, 5.4 on the fins, 6.7 on the lid and 6.4 for radiation, giving a conductance of about 1.18 W/K (the TRL 2 estimate was 1.3 W/K). Heat is taken at minimum pack voltage, where the current is highest.

*Table 4. Case and MOSFET temperatures at 40 °C ambient, shaded, with the coil economizer holding the contactor at about 1 W.*

| Case | Heat in the module | Case surface | MOSFET junction |
| --- | --- | --- | --- |
| Reference, 250 W on SwapCell | 6.5 W | 47.0 °C | about 49 °C |
| CargoMule, 250 W | 7.6 W | 48.0 °C | about 51 °C |
| Heavy, 350 W on 8S LFP | 16.5 W | 55.6 °C | about 64 °C |
| 500 W on 8S LFP (information) | 29.2 W | 65.2 °C | about 81 °C |

**Floor joint (MTC-DDR-003).** The controller, contactor and fuse block sit on the floor plate, which is a separate plate under the finned tube. Their heat (all of it except the supervisor's 0.7 W) crosses a 0.2 mm film of thermally conductive sealant on 2,380 mm² of wall and port end faces, a conductance of about 11.9 W/K. That puts the floor plate about 0.5 K above the walls in the reference case (47.5 °C) and 1.3 K above them in the heavy case (**56.9 °C**, 3.1 K under the R9 limit), and lifts the MOSFET junctions by the same amount (about 65 °C heavy). The floor plate's own underside is ignored, so these figures are on the safe side.

The derate to 350 W at 24 V (MTC-DDR-001 item 9) is needed: 500 W misses the 60 °C target by about 5 K. At 350 W the margin is 4.4 K on the walls and depends on the controller assumptions:

- Phase current twice the bus current (a motor running well below its base speed, as a walk-behind host with a fast winding would): 33.7 W, **68.4 °C**.
- Twice the phase resistance (low-cost controller MOSFETs): 25.4 W, **62.4 °C**.
- Sun on the lid (information; R9 assumes shade): 10.8 W absorbed, 56.2 °C in the reference case and 63.8 °C in the heavy case.

**Coil economizer.** The contactor coil takes 4 W at pull-in and, without help, the same while held, which was about half of the reference-case heat. A coil economizer module on the supervisor carrier board (BOM line 3, USD 4.00; decided on 2026-10-02) applies full voltage for 0.5 s and then holds the coil by pulse-width modulation at about 1 W, its own loss included. It saves 3.5 W of input heat in steady state. The auxiliary supply is now about 29 % of the reference-case heat. The currents and fuse sizes of section 3 keep the 4 W pull-in figure, which is the conservative case. The economizer sits after the safety loop's break in the coil supply, so a stop still removes its input (section 5). With the economizer the heavy case is 16.5 W, 55.6 °C on the walls and 56.9 °C on the floor plate. **R9 is met on paper** for the reference and heavy cases (it was at risk in the heavy case); it is not met in the two sensitivity cases above, or in sun, so R9 still rests on shade and on the controller assumptions.

## 5. Emergency stop timing (R3)

Channel A of the e-stop opens the contactor coil circuit directly. With a 24 V Zener across the coil, the coil current decays from 333 mA to its release point in 2.9 ms (τ = 8.3 ms); a plain diode takes 15.5 ms. Adding 10 ms for contact opening and bounce, 10 ms for armature travel, 5 ms of arc, 2.2 ms during which the bus capacitors (0.69 J) keep the motor running and 7.2 ms for the coil economizer's output capacitor to run down (at most 100 uF, specified) gives about **37 ms modeled** with the Zener and 50 ms with a plain diode.

The worst case uses the release time the contactor must meet as a selection criterion (50 ms or less with its suppressor): 10 + 50 + 5 + 2.2 + 7.2 ≈ **74 ms**, inside the 100 ms of R3. In 74 ms a host at 25 km/h travels about 52 cm and a walk-behind machine at 1.5 m/s about 11 cm (69 cm and 15 cm in the full 100 ms). **Coil economizer and the 50 ms drop-out.** The safety loop opens the 12 V supply upstream of the economizer, so a stop removes its input and not just the coil's. The coil is then held at about 83 mA mean (against 333 mA at pull-in), so the current falls to the release point in about 0.6 ms through the Zener, faster than from full current; the 2.9 ms figure above is kept as the bound. The economizer's output capacitor is limited to 100 uF so that it can hold the coil only a further 7.2 ms, which the worst case now includes. The 50 ms release limit stays a selection criterion for the contactor. No firmware is in this path, so R3 holds with both processors failed. **R3 is met on paper.** R4 (no automatic restart) is met by circuit review: the coil loop can close only after the key is cycled, and the supervisor closes its switch only at zero throttle with the brakes released and no fault.

## 6. Precharge (R8)

With 100 Ω and 1,000 µF the time constant is 100 ms. At the 60 V upper bound of R1 the peak precharge current is 0.60 A and the residual at closure 0.15 V. The supervisor closes the contactor after six time constants (0.6 s) and only if the controller reports a bus voltage of at least 90 % of the pack voltage, which catches a shorted bus or a missing capacitor bank. The residual difference at closure is 0.07 to 0.14 V, and the closure inrush is 1.0 A (SwapCell), 1.2 A (CargoMule) and 1.3 A (8S LiFePO4), under the 5 A target. Peak precharge current is 0.55 A at 54.6 V, and the resistor absorbs 1.49 J per start. Into a shorted bus it would dissipate 30 W; a 1 s timeout limits that to 30 J, which a 10 W aluminum-clad resistor survives. **R8 is met.** The TRL 2 figure of 0.5 s (five time constants) left up to 8 A at closure on a low-resistance LiFePO4 pack, so the closure point moves to 0.6 s.

## 7. Speed sensing and reaction times (R5 to R7)

*Table 5. Speed sensor pulse rates with eight magnets.*

| Wheel | At 1.5 m/s | At 25 km/h |
| --- | --- | --- |
| 20 in, 1.57 m (CargoMule) | 7.6 pulses/s (131 ms period) | 35.4 pulses/s (28 ms) |
| 700C or 28 in, 2.15 m (SunSpoke) | 5.6 pulses/s (179 ms) | 25.8 pulses/s (39 ms) |
| 200 mm hub, 0.63 m (walk-behind) | 19.0 pulses/s (52 ms) | 88.2 pulses/s (11 ms) |

Counting pulses over 0.5 s is too coarse at walking pace (one count is 26 % of the reading). The supervisor therefore times each period with a 1 MHz timer (resolution about 0.0035 % at 25 km/h); magnet placement jitter of about 2 % leaves a fivefold margin to the 10 % overspeed threshold. Overspeed held for 0.5 s opens the contactor in about 0.71 s at 1.5 m/s and 0.60 s at 25 km/h on a 20 in wheel, including one pulse period and the 67 ms contactor budget. **R6 is met on paper.** The wheel circumference and magnet count are configuration values; a wrong value moves the limit, so they belong on the fault chart.

Timing budgets: a brake switch sets the controller command to zero in about 75 ms (10 ms debounce, 5 ms loop, 10 ms CAN, 50 ms current ramp), inside 200 ms (**R5 met on paper**). A lost controller heartbeat takes about 170 ms (100 ms timeout plus loop, CAN and ramp), and the contactor is opened as well; a BMS fault, which SwapCell and CellGuard send on change, takes about 80 ms (**R7 met on paper**).
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

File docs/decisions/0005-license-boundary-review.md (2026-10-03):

---
doc_id: MTC-DDR-005
title: MotionCore license boundary review
project: MotionCore
doc_type: Design decision record
version: "0.1"
status: Draft
date: '2026-10-02'
author: Amish Chadha
license: CERN-OHL-S-2.0
revisions:
- version: "0.1"
  date: '2026-10-02'
  author: Amish Chadha
  change: Short written review of the license boundary between the VESC firmware (GPL-3.0) and the supervisor firmware (MIT), as decided on 2026-10-02
---

# 0005: License boundary review

- **Date:** 2026-10-02
- **Status:** proposed (a short review for Amish; not legal advice)

## Context

On 2026-10-02 Amish decided that a short written review of the license boundary is done before any firmware is published, and that a lawyer is called in only if a commercial partner will ship the module (R13; MTC-DEC-001). No firmware is published and none exists beyond a labeled sketch.

The parts involved: the hardware (CERN-OHL-S-2.0); the supervisor firmware, MIT, running alone on its own STM32G0B1-class processor; and the motor controller's unmodified VESC firmware, GPL-3.0, running on a separate VESC-class controller. The two processors exchange messages over an internal CAN bus at 500 kbit/s.
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

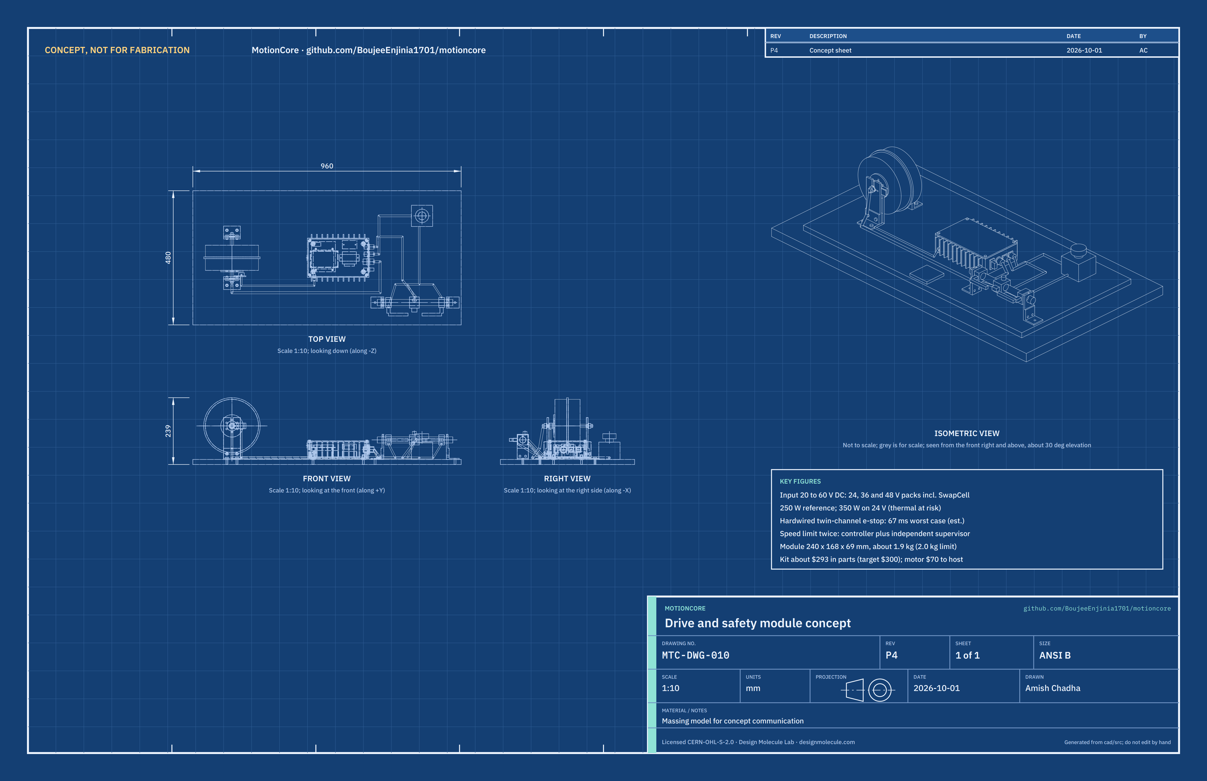
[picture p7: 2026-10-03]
media/concept-blueprint.png

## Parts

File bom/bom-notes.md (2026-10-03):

# BOM notes

- Costs are indicative USD prices for single prototype quantities, estimated in September 2026. Supplier types are given; specific suppliers are not yet selected.
- Item numbers 1 to 15 match the callouts in `media/exploded.png`. Item 15, the bench rig, belongs to the prototype only (MTC-DDR-003).
- **Budget scope (MTC-DDR-001 item 1, decided by Amish, 2026-09-25: go with recommendation):** the USD 300 `budget_usd` is a value-engineering target (a hypothetical control target, not a limit; Amish, 2026-10-01) for the MotionCore kit, items 2 to 14. The reference hub motor (item 1) is a named part of interface v0.1 but is costed to each host.

*Table 1. Totals (checked by `docs/04-calcs/sizing.py`, MTC-CAL-001 section 10).*

| Scope | Items | Total | Against the USD 300 value-engineering target |
| --- | --- | --- | --- |
| MotionCore kit | 2 to 14 | USD 297 | USD 3 under the target |
| Reference motor, costed to the host | 1 | USD 70 | Not in the MotionCore total |
| Bench rig, prototype only | 15 | USD 35 | Not in the MotionCore total |
| Complete kit with reference motor | 1 to 14 | USD 367 | For host cost estimates |

- Changes at TRL 3: the supervisor board rose from $22 to $30 (second CAN transceiver and an 18 to 75 V auxiliary buck); pads and consumables from $6 to $8 (rubber isolation pads with M6 studs). Specifications now carry the selection criteria from MTC-CAL-001: fuse rated 60 V DC or more with 1 kA breaking capacity (58 V before R1 was raised to 60 V, MTC-DDR-002), contactor breaking 50 A at 60 V DC and releasing within 50 ms with a 24 V Zener, 4 mm² pack leads for 24 V hosts. The controller overvoltage fault is set to 66 V (was 60 V) and the XT90 is provisional pending a sealed-connector evaluation (MTC-DDR-002). None of these changes alters a price.
- The battery pack, BMS and host mechanics (wheels, brakes, frame, pack receptacle and its SwapCell INTERLOCK coding resistor) are not included.
- Changes for construction (MTC-DDR-003, 2026-10-01): item 6 becomes a cut length of finned extrusion on a floor plate (USD 22 to 30); item 7 a flat lid on an EPDM gasket (unchanged price); item 8 sockets through the wall with flanges and frames, an M8 speed sensor socket and a membrane vent (USD 18 to 24); item 10 brake levers with built-in switches (USD 4 to 7 each); item 12 adds the speed sensor plug (USD 6 to 8); item 13 adds the safety loop branch (USD 18 to 20); item 14 adds rivet nuts and lid and floor fixings (USD 8 to 12); item 15 added. The kit rises from USD 265 to USD 293.
- Decided on 2026-10-02 (MTC-DEC-001) and carried into the BOM the same day: a contactor coil economizer is fitted (module in line 3, USD 4.00 extra, so line 3 is USD 34.00; the carrier board grows 20 mm to 85 x 108 mm to take it), wired so the safety loop breaks the coil supply upstream of it. Not in the BOM lines: the XT90 (line 8) is for the bench prototype only, pending the sealed power connector evaluation (keyed, IP67 mated, 40 A or more at 60 V DC; first candidate class an industrial IP67 single-pole connector such as Amphenol's SurLok Plus); the M8 speed socket is part of interface v0.2.

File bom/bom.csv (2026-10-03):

item | qty | spec | supplier | unit_cost_usd | make_buy | notes
1 Reference hub motor | 1 | 250 W geared brushless hub motor, 36 or 48 V winding, Hall sensors and temperature sensor, 9-pin waterproof plug, freewheel clutch | E-bike motor distributor (geared hub class) | 70.00 | buy | Indicative price; reference part named in interface v0.1; costed to each host and excluded from the MotionCore total (MTC-DDR-001 item 1)
2 Motor controller | 1 | VESC-class controller, 75 V MOSFET stage (about 1.6 mOhm per FET), 50 A continuous phase current class, about 1000 uF bus capacitance, CAN, unmodified open firmware (GPL-3.0); overvoltage fault set to 66 V | VESC-compatible hardware vendor (for example Trampa or Flipsky class) | 85.00 | buy | Indicative price; mounted to the enclosure floor with a thermal pad; bus capacitance and MOSFET resistance to confirm from the chosen part (MTC-CAL-001)
3 Safety supervisor board | 1 | Microcontroller with two CAN controllers (STM32G0B1 class) and two transceivers (internal 500 kbit/s to the controller, external 250 kbit/s to SwapCell or CellGuard), 18 to 75 V input buck to 12 V 10 W for the coil and logic, isolated speed input, throttle and brake inputs, e-stop channel B input, MOSFET enable switch for the coil, precharge switch, USB fault log; plus a contactor coil economizer module (12 V, 1 A, full voltage for 0.5 s at pull-in then PWM hold at about 1 W, output capacitor 100 uF or less) wired after the loop break, 24 x 14 x 8 mm on the carrier board | Electronics distributor plus small-run PCB service | 34.00 | make | Indicative price; USD 30 for the board and modules as before plus USD 4 for the economizer module (small PWM hold module class, USD 3 to 5 at quantity 1); firmware is a labeled sketch only at TRL 3 (MIT)
4 Main DC contactor | 1 | Sealed DC contactor, 100 A continuous, able to break at least 50 A at 60 V DC, 12 V coil 5 W or less, release time 50 ms or less with a 24 V Zener suppressor across the coil | EV or industrial contactor supplier | 25.00 | buy | Indicative price; release time and DC breaking rating are selection criteria from MTC-CAL-001 section 5
5 Precharge and main fuse block | 1 | 100 ohm 10 W aluminum-clad precharge resistor, sealed fuse holder, blade fuse rated 60 V DC or more with at least 1 kA breaking capacity: 20 A for 36 and 48 V hosts, 40 A for 24 V hosts | Electronics distributor | 12.00 | buy | Indicative price; fuse size per host (MTC-CAL-001 section 3)
6 Enclosure: finned tube and floor plate | 1 | Finned enclosure extrusion, 220 x 140 mm outside the walls, 3 mm walls, 11 fins per long side 3 x 14 mm on a 19 mm pitch, four screw ports tapped M4 in the inside corners, cut 56 mm long so the fins stand vertical; 220 x 140 x 3 mm 6061 floor plate; thermally conductive silicone sealant for the floor joint; clear anodized | Extrusion or heat-sink enclosure supplier; plate from a metal stockist | 30.00 | make | Indicative price; tube cut and drilled and floor plate cut and drilled in the workshop (MTC-DDR-003); doubles as the controller heat sink; profile to confirm when bought (MTC-DEC-001)
7 Lid and lid gasket | 1 | 220 x 140 x 3 mm 5052 or 6061 aluminum sheet lid, clear anodized; 1 mm closed-cell EPDM gasket cut as a frame; four M4 x 10 stainless button-head screws with bonded sealing washers | Metal stockist and hardware shop | 6.00 | make | Indicative price; flat lid on a flat gasket replaces the concept lid lip, which clashed with the corner ports (MTC-DDR-003)
8 Connector panel | 1 | XT90 anti-spark socket in a two-screw panel frame; 9-pin waterproof motor socket, nut mounted; M12 8-pin A-coded socket (safety loop) and M12 5-pin B-coded socket (command and CAN), both with a 20 mm square four-screw flange; M8 4-pin A-coded socket for the speed sensor; adhesive membrane vent, 20 mm, over a 5 mm hole; M3 screws and nuts | Connector distributor | 24.00 | buy | Indicative price; fitted straight through the 3 mm end and side walls, so no separate panel plate (MTC-DDR-003); XT90 not sealed (R10 at risk) and provisional until a sealed power connector is evaluated (MTC-DDR-002)
9 E-stop station | 1 | 22 mm red mushroom-head pushbutton on yellow enclosure, twist release, two normally closed contact blocks with positive opening | Industrial controls supplier | 15.00 | buy | Indicative price
10 Brake levers with interlock switches | 2 | E-bike brake levers for 22.2 mm bars with built-in normally closed cut-off switches, sealed, with keyed leads; on a host the switches go on the host brakes | E-bike parts supplier | 7.00 | buy | Indicative price per lever; levers replace bare switches so they can clamp on the bench handlebar (MTC-DDR-003)
11 Key switch and throttle pod | 1 | Two-position key switch (enable and reset) and hall-effect thumb throttle (0.8 to 4.2 V output) in one pod that clamps on a 22.2 mm bar | E-bike or industrial parts supplier | 12.00 | buy | Indicative price
12 Independent speed sensor | 1 | Eight-magnet ring with six 5.5 mm holes on a 44 mm circle (bolts to the hub motor's six-bolt disc mount) and sealed Hall pickup with lead and M8 4-pin plug | E-bike parts supplier | 8.00 | buy | Indicative price; read only by the supervisor
13 Wiring harness | 1 | Pre-made leads with keyed waterproof connectors: motor lead, safety loop lead to the e-stop station with a branch to both brake levers and the key, command lead to the pod, speed sensor lead; 2.5 mm2 pack leads with XT90 plug for 36 and 48 V hosts or 4 mm2 for 24 V hosts; shielded signal pairs, spiral wrap, adhesive cable clips | Connector distributor | 20.00 | make | Indicative price
14 Pads, rivet nuts, standoffs and fixings | 1 | Four 16 x 3 mm rubber isolation pads (6.5 mm hole); four M6 closed-end steel rivet nuts for 0.5 to 3 mm grip; four 35 mm M3 hex standoffs; M3 and M4 stainless screws; four M4 x 8 countersunk floor screws; 1 mm thermal pad; medium thread sealant; cable ties and labels | Local hardware shop and fastener supplier | 12.00 | buy | Indicative price; rivet nuts replace the concept's cast M6 bosses, which a plate floor cannot carry (MTC-DDR-003)
15 Bench rig (prototype only) | 1 | 18 mm plywood board 960 x 480 mm; two motor uprights 60 x 6 mm aluminum flat bar 150 mm long; two bar posts 40 x 6 mm flat bar 90 mm long; four feet from 40 x 40 x 4 mm aluminum angle; Hall pickup bracket 20 x 3 mm flat bar; 22.2 mm aluminum handlebar stub 270 mm long; four M6 x 30 module bolts with washers; M6 and M4 bolts, nyloc nuts and washers; wood screws for the e-stop station | Local hardware shop and metal stockist | 35.00 | make | Indicative price; holds the module, the reference motor with its wheel off the board, the e-stop and the controls for the first bench build (MTC-DDR-003); not part of the MotionCore kit and excluded from its total

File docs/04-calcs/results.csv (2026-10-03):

id | value | target | status
R10 | XT90 power socket is not sealed; a sealed power connector is to be evaluated before interface v0.1 is frozen (MTC-DDR-002); M12 and motor plug are IP65 or better when mated; vibration not analyzed | IP65 mated; survive road and stair vibration | At risk
R11 | Interface v0.1 adopted: XT90 (provisional), 9-pin motor plug, M12 A-coded safety loop, M12 B-coded command, plus an M8 speed sensor socket (MTC-DDR-003, to confirm); fit time needs a timed fit | One keyed connector set; fit in 2 h | Not verifiable at TRL 3
R1 | 20 to 60 V covered by a 75 V controller and an 18 to 75 V aux buck; SwapCell 39.0 to 54.6 V, CargoMule 30.0 to 43.8 V, 8S LFP 20.0 to 29.2 V and CellGuard 16S LFP up to 58.4 V inside the range | 20 to 60 V DC; 75 V transient | Met (design review)
R2 | 250 W: 6.9 A at 46.8 V; 350 W: 17.7 A at 25.6 V; 750 W for 10 s: 21.9 A (SwapCell), 40.9 A (8S LFP); CargoMule's 15 A pack limit caps its peak at about 414 W; heavy case thermal met with the coil economizer (R9) | 250 W reference; 350 W heavy (8S LFP); 750 W for 10 s | Met (paper)
R3 | 74 ms worst case (37 ms modeled); hardwired channel A, no firmware in the path | 100 ms; works with both processors failed | Met (paper)
R4 | Coil loop needs key reset; supervisor closes its switch only at zero throttle, brakes released, no faults | No automatic restart | Met (design review)
R5 | 75 ms from either switch to zero torque; brake coil powered from the loop | 200 ms | Met (paper)
R6 | Period method, 2 % jitter vs 10 % threshold; trip in 0.71 s (1.5 m/s) and 0.60 s (25 km/h) | 10 % for 0.5 s opens the contactor | Met (paper)
R7 | 170 ms worst (controller heartbeat); throttle range and BMS flag faster | 200 ms | Met (paper)
R8 | Peak 0.55 A through the resistor; 1.3 A at closure (worst pack); ready in 0.6 s | Under 5 A; ready within 1 s | Met
R9 | 47.0 C reference; 55.6 C heavy at 350 W (floor plate 56.9 C), with the coil economizer; the sensitivity cases (twice the phase current, clone MOSFETs) reach 62 to 68 C (65.2 C at 500 W); shade assumed | 60 C or less at 40 C ambient | Met (paper)
R12 | 240 x 168 x 69 mm; 1.92 kg | 250 x 170 x 70 mm; 2.0 kg | Met
R13 | Supervisor firmware MIT on its own processor; VESC firmware unmodified GPL-3.0 on the controller; CAN link only; formal license review open | Open hardware and firmware | Met (design review)
R14 | USD 297 for items 2 to 14 (reference motor USD 70 costed to the host; bench rig USD 35, prototype only) | Value-engineering target USD 300 | Under the target by USD 3 (indicative prices)

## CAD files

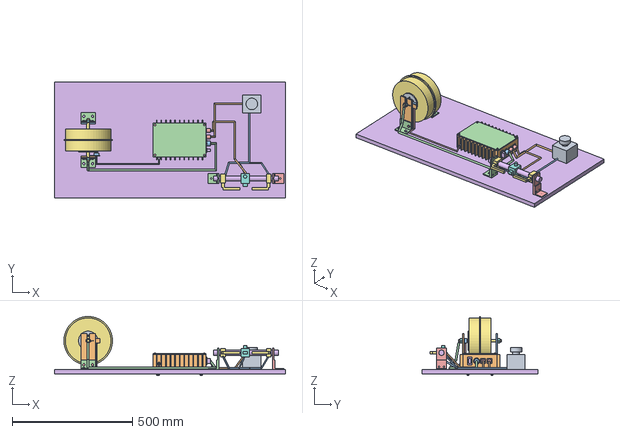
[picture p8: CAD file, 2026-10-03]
cad/step/motioncore-kit.step
960.0 x 480.0 x 245.5 mm

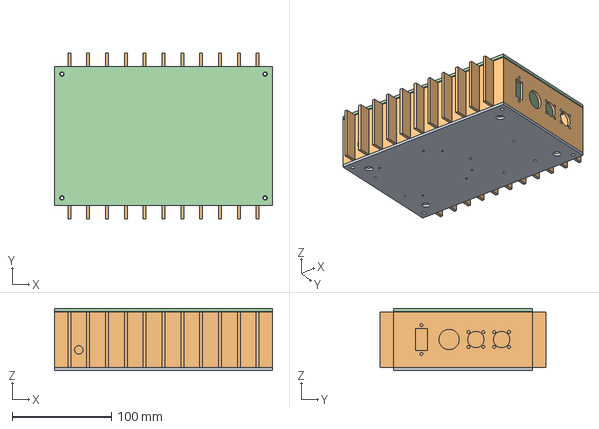
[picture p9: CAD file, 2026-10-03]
cad/step/motioncore-enclosure.step
220.0 x 168.0 x 63.0 mm

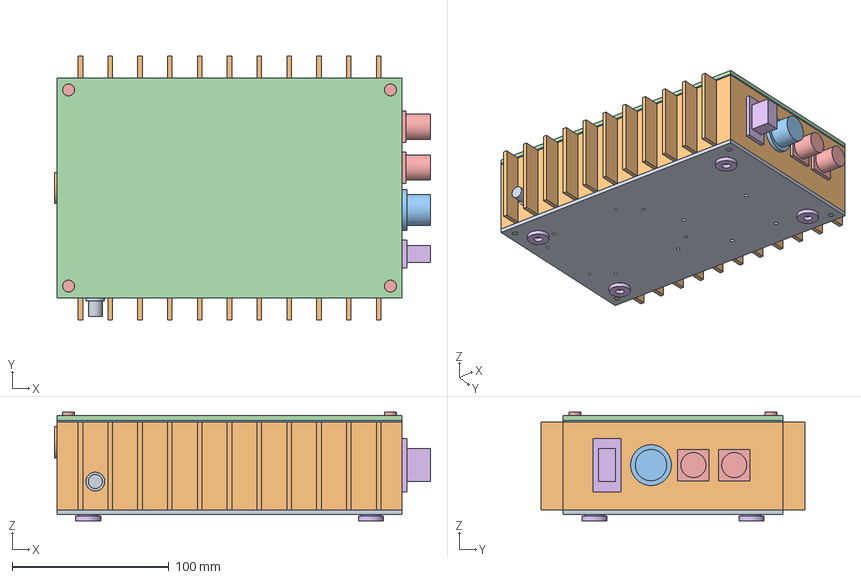
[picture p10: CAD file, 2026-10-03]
cad/step/motioncore-module.step
239.5 x 168.0 x 69.2 mm

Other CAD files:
cad/stl/motioncore-enclosure.stl
cad/stl/motioncore-kit.stl
cad/stl/motioncore-module.stl

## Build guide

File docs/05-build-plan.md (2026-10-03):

---
doc_id: MTC-BLD-001
title: MotionCore prototype build plan
project: MotionCore
doc_type: Build plan
version: "0.3"
status: Draft
date: '2026-10-02'
author: Amish Chadha
license: CERN-OHL-S-2.0
revisions:
  - version: "0.1"
    date: '2026-10-01'
    author: Amish Chadha
    change: First build plan, with pictures by component and step; design made constructable (MTC-DDR-003)
  - version: "0.2"
    date: '2026-10-02'
    author: Amish Chadha
    change: "MTC-DDR-003 accepted (2026-10-02)"
  - version: "0.3"
    date: '2026-10-02'
    author: Amish Chadha
    change: 'Contactor coil economizer on the supervisor carrier board (board 85 x 108 mm), coil wiring through the loop break, first check; cost USD 297'
---

# MotionCore prototype build plan

**Plan, not yet built.** How to build the first proof-of-concept prototype, component by component. Building and testing to it is TRL 4 work. Decisions still to be made are kept in the design decisions register ([docs/06-design-decisions.md](06-design-decisions.md)), not here.

## 1. What you are building

Figure 1. Every component, pulled apart and numbered in build order

*Figure 1. Every component pulled apart and numbered in build order: the module (1 to 12), then the bench rig and devices (13 to 25).*

The prototype is one MotionCore module bolted to a plywood bench board through its own host mounting points, with the reference hub motor held by its axle in two slotted uprights so the wheel turns clear of the board, an e-stop station screwed beside it and a short handlebar carrying the two brake levers and the key and throttle pod. The module is a finned aluminum tube standing on a floor plate, closed by a gasketed lid, with the motor controller, the contactor, the precharge and fuse block and the safety supervisor board inside and five sockets through its walls. Figure 1 shows the 25 components in the order you make or fit them. Ten are made in a small workshop: the floor plate, the finned tube (cut and drilled), the supervisor carrier board, the lid and its gasket, the bench board, the motor uprights, their feet, the Hall pickup bracket, the bar posts and the handlebar stub; the harness is made up from bought leads. Everything else is bought and fitted. The work is cutting and drilling aluminum plate, bar, angle and tube, tapping, setting rivet nuts, cutting plywood, and wiring bought modules with crimped and soldered joints. The parts cost about USD 297 for the MotionCore kit, plus USD 70 for the reference motor and USD 35 for the bench rig, from the bill of materials.

> **Safety:** MotionCore switches a battery that can drive several hundred amperes into a short circuit and turns a motor. Build and wire the module with no battery in the room; keep the main fuse out until section 6 says otherwise; power it first from a current-limited bench supply; and never run the motor unless the wheel is clear of everything, a second person is at the e-stop and the e-stop has been checked that day. Cut aluminum edges are sharp: deburr everything. Wear eye protection for all cutting, drilling and soldering.

## 2. What changed to make it buildable

The concept showed what MotionCore does; some of its parts could not be made, fixed or connected as drawn. Each change below keeps what the module does, and all of them are recorded in decision record MTC-DDR-003, which Amish accepted on 2026-10-02.

*Table 1. Changes from the concept.*

| Component | The concept had | The buildable design has | Why |
| --- | --- | --- | --- |
| Enclosure body | An extruded box with a closed floor and vertical fins, which an extrusion cannot have | A 56 mm length of finned enclosure extrusion standing on a separate 3 mm floor plate, joined by conductive sealant and four screws into the corner ports (Figures 2 to 4) | One wall thickness and vertical fins, as the concept; the controller still sits on aluminum bolted to the fins |
| Lid | A lip inside the walls that clashed with the corner ports, and no fixing | A flat lid on a 1 mm gasket, four screws into the same ports (Figures 11, 12) | Ports take both floor and lid screws |
| Host mounting points | M6 inserts in cast bosses | Closed-end M6 rivet nuts in the floor plate, rubber pads under their flanges (Figure 5) | Same four M6 on 180 x 100 mm; the floor stays sealed |
| Supervisor board | Standoffs standing inside the controller | A wider board (85 x 108 mm, with a strip for the coil economizer) with its standoffs beside the controller (Figure 9) | No overlap; 10 mm of air over the controller; room for the economizer |
| Connector panel | A plate outside a closed wall, connectors closer than their own flanges | Sockets straight through the end wall, spaced so every flange and nut has room (Figures 3, 6) | Buildable, and the power socket can be swapped by recutting one hole |
| Precharge and fuse block | In the path of the socket bodies | Beside the contactor | Room behind the end wall for sockets and wires |
| Speed sensor | No socket and no free pins | Its own small M8 socket between two fins (Figure 3) | Brings the sensor in without growing the module |
| Vent | Listed but not drawn | Adhesive membrane vent on the far end wall | Keeps the module inside 250 mm long |
| Speed ring and pickup | Floating beside the motor | Ring bolted to the motor's disc mount; pickup on a bracket on the motor upright (Figure 17) | Real fixings, 3.5 mm sensing gap |
| Reference kit layout | Loose on a bench, motor standing on its shell | A bench rig: board, motor uprights, bar posts and handlebar (Figures 13 to 21 and steps 8 to 16) | The wheel can turn clear of the board for first runs |
| Brake switches | Blocks with no mounting | Brake levers with built-in switches, clamped on the handlebar | Real parts that clamp where a host's controls go |
| Harness | Leads routed to the wrong devices | One lead per socket, with the key and brake levers on the safety loop | Matches the interface |

## 3. Making the components

Make and check each component before the assembly step that needs it. Sizes are in millimetres. The module's **connector end** carries the four main sockets; the **far end** is opposite it. Its **socket side** is the long side with the small speed socket; the **plain side** is the other. Workshop tolerance is 0.5 mm unless a step says otherwise; drawings do not carry tolerances before TRL 4.

### 3.1 Floor plate

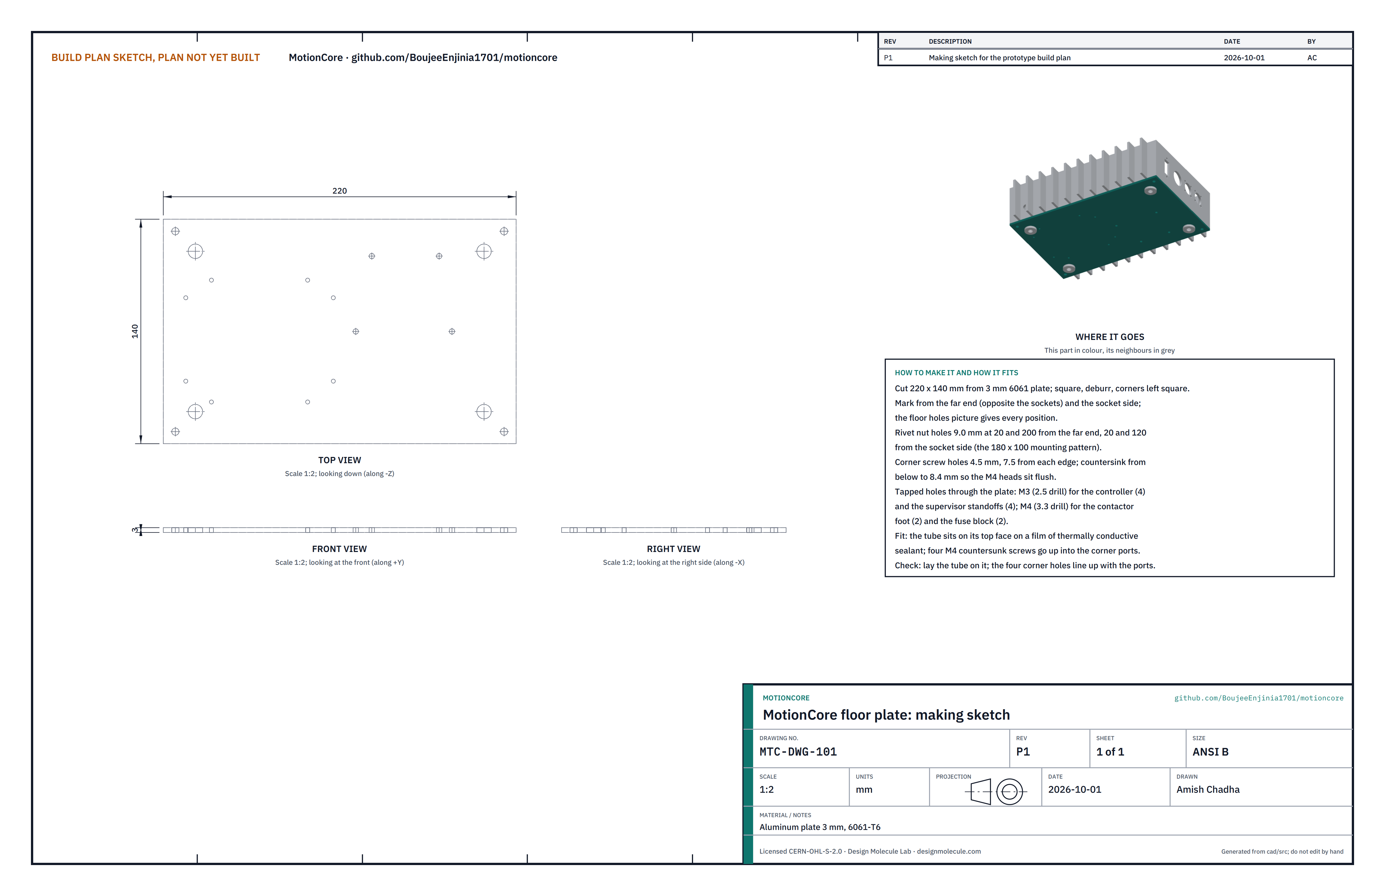
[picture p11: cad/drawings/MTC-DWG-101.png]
Figure 2. Making sketch of the floor plate


*Figure 2. Floor plate making sketch (MTC-DWG-101).*

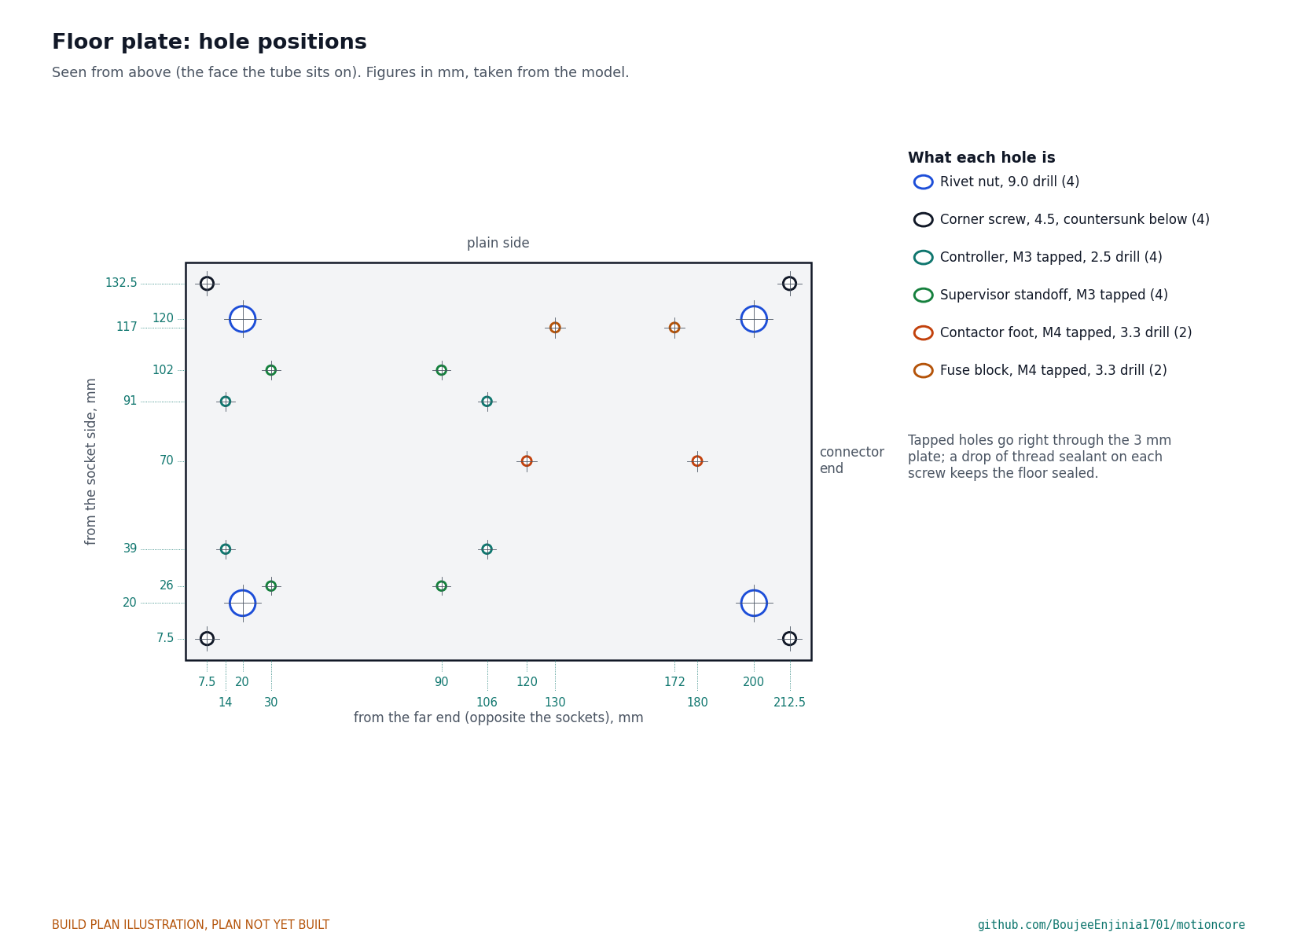
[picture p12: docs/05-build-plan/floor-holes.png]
Figure 2a. Floor plate hole positions


*Figure 2a. Every hole, measured from the far end and from the socket side.*

**What it is and what it is made from.** The bottom of the module and the plate everything inside is fixed to; it carries the four host mounting points and conducts the controller's heat into the finned walls. Aluminum plate 3 mm thick, 6061-T6, cut to 220 x 140 mm.

**How to make it.**

1. Cut the blank to 220 x 140 mm, square, and deburr. Mark the far end and the socket side on the top face.
2. Mark every hole from Figure 2a, measuring from the far end and from the socket side.
3. Rivet nut holes: four 9.0 mm holes at 20 and 200 from the far end, 20 and 120 from the socket side. Check the size against the rivet nut's datasheet before the last drill.
4. Corner screw holes: four 4.5 mm holes, 7.5 in from each end and each side. Countersink from the bottom face to 8.4 mm across so M4 countersunk heads sit flush.
5. Controller holes: four, drilled 2.5 mm and tapped M3 through, at 14 and 106 from the far end, 39 and 91 from the socket side. Check the pattern against your controller's mounting holes first and move these to suit.
6. Supervisor standoff holes: four, drilled 2.5 mm and tapped M3 through, at 30 and 90 from the far end, 26 and 102 from the socket side.
7. Contactor foot holes: two, drilled 3.3 mm and tapped M4 through, at 120 and 180 from the far end, 70 from the socket side.
8. Fuse block holes: two, drilled 3.3 mm and tapped M4 through, at 130 and 172 from the far end, 117 from the socket side.
9. Deburr every hole on both faces and clean off all chips and oil.

**How it fits the parts next to it.** The tube stands on its top face, flush with its edges all round, on a thin film of thermally conductive sealant, and four M4 countersunk screws come up through the corner holes into the tube's corner ports (Figure 4). The rivet nuts go in from below (Figure 5). The controller, standoffs, contactor and fuse block sit on its top face on screws into the tapped holes.

**Check before moving on.** Lay the tube on the plate: the four corner holes line up with the four ports, and every edge is flush within 0.5 mm.

### 3.2 Finned tube

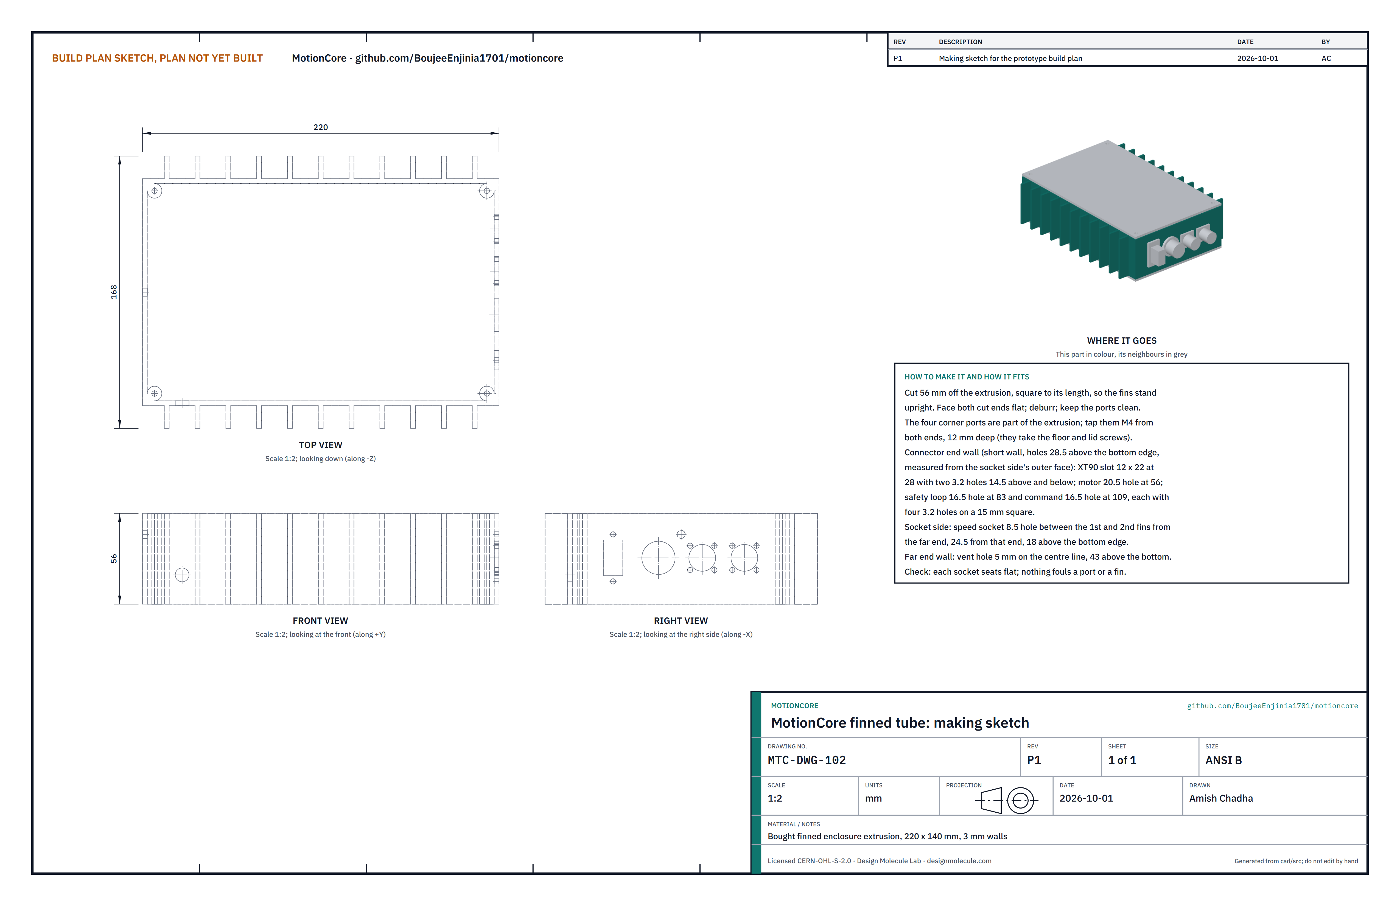
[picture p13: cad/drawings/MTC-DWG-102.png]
Figure 3. Making sketch of the finned tube


*Figure 3. Finned tube making sketch (MTC-DWG-102).*

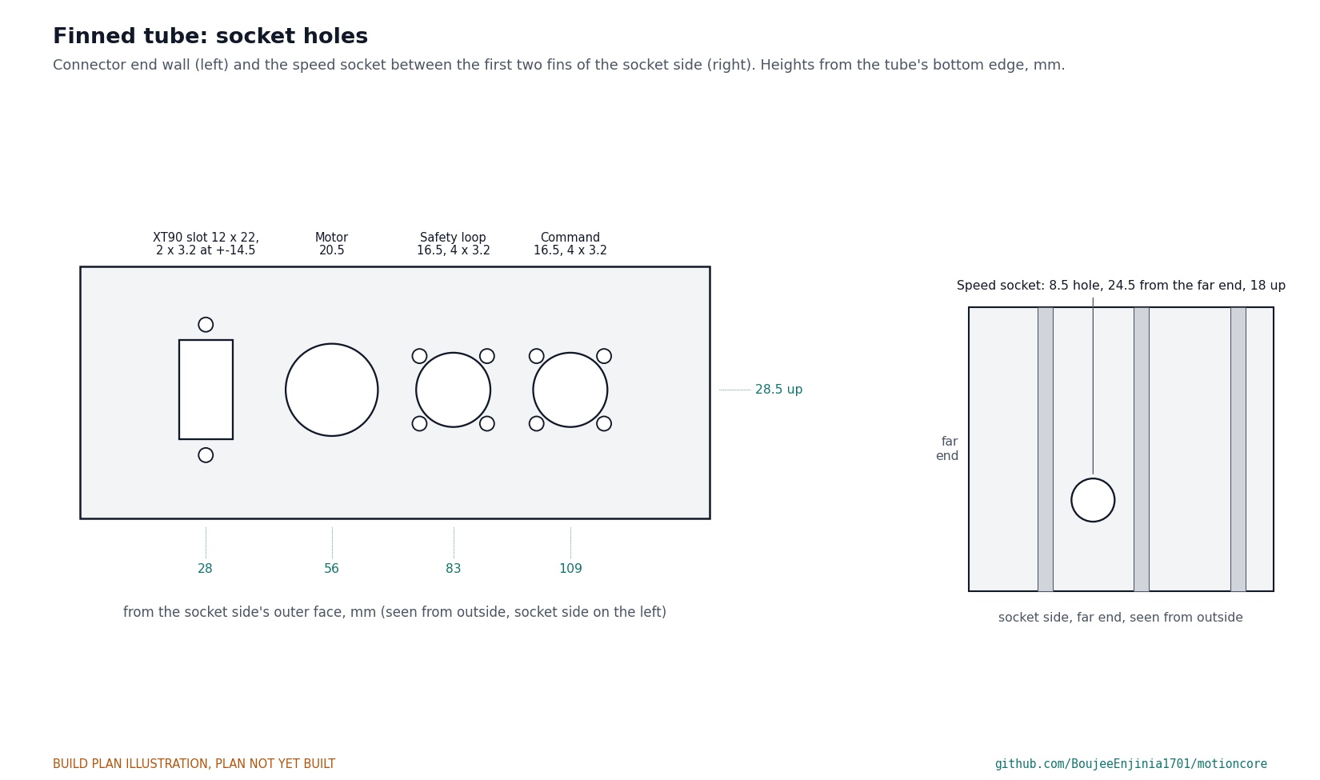
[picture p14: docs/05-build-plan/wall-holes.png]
Figure 3a. Socket hole positions


*Figure 3a. Holes in the connector end wall, seen from outside, and the speed socket hole in the socket side.*

**What it is and what it is made from.** The four walls and the fins of the module, and its heat sink. A bought finned enclosure extrusion, 220 x 140 mm outside the walls, 3 mm walls, eleven 3 x 14 mm fins on a 19 mm pitch along each long side and four screw ports in the inside corners, cut to 56 mm long so the fins stand upright.

**How to make it.**

1. Cut 56 mm off the extrusion with a fine-toothed saw, square to its length. Face both cut ends flat on a sheet of abrasive paper on a flat plate; they carry the floor and lid seals.
2. Tap the four corner ports M4, 12 mm deep from both ends.
3. Mark the connector end wall from Figure 3a. All four socket centres are 28.5 above the bottom edge, measured along the wall from the socket side's outer face: power socket at 28, motor at 56, safety loop at 83, command at 109.
4. Power socket: a 12 wide by 22 tall slot, centred at 28. Chain drill inside the outline, file to the line, then drill two 3.2 mm holes on its centre line, 14.5 above and below its centre, for the frame screws.
5. Motor socket: a 20.5 mm hole at 56. Safety loop and command: 16.5 mm holes at 83 and 109, each with four 3.2 mm holes on a 15 mm square round it. Use a step drill; check each size on the socket's datasheet before the last step.
6. Speed socket: an 8.5 mm hole in the socket side, between the first and second fins from the far end, 24.5 from the far end and 18 above the bottom edge.
7. Vent: a 5 mm hole in the far end wall on its centre line, 43 above the bottom edge.
8. Deburr every hole inside and out and clean the tube.

**How it fits the parts next to it.**

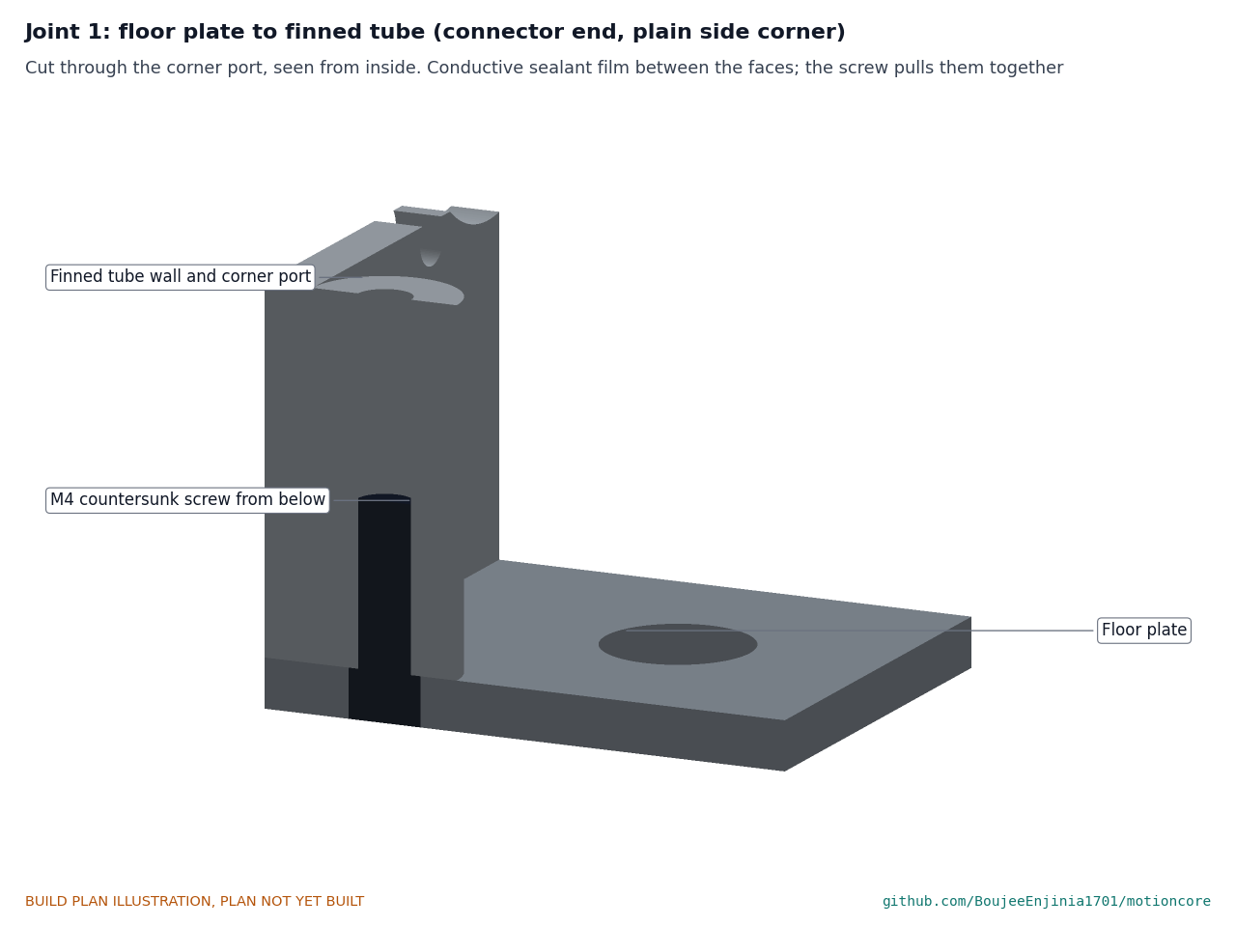
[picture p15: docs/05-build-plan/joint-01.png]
Figure 4. Joint 1: floor plate to tube


*Figure 4. The tube's wall and corner port stand on the floor plate; the screw pulls them together through the sealant film.*

The tube's bottom end sits flat on the floor plate, edges flush. Spread a thin, even film of thermally conductive silicone sealant on the floor plate where the walls and ports land, keeping it out of the port holes, fit the four screws and tighten them evenly; wipe off what squeezes out. The film seals the joint and carries the controller's heat into the fins; it should end up about 0.2 mm thick. The lid seals on the top end (Figure 12).

**Check before moving on.** The tube stands square on a flat plate without rocking; each socket and its screws fit their holes; no hole breaks into a fin or a port.

### 3.3 Rivet nuts and pads

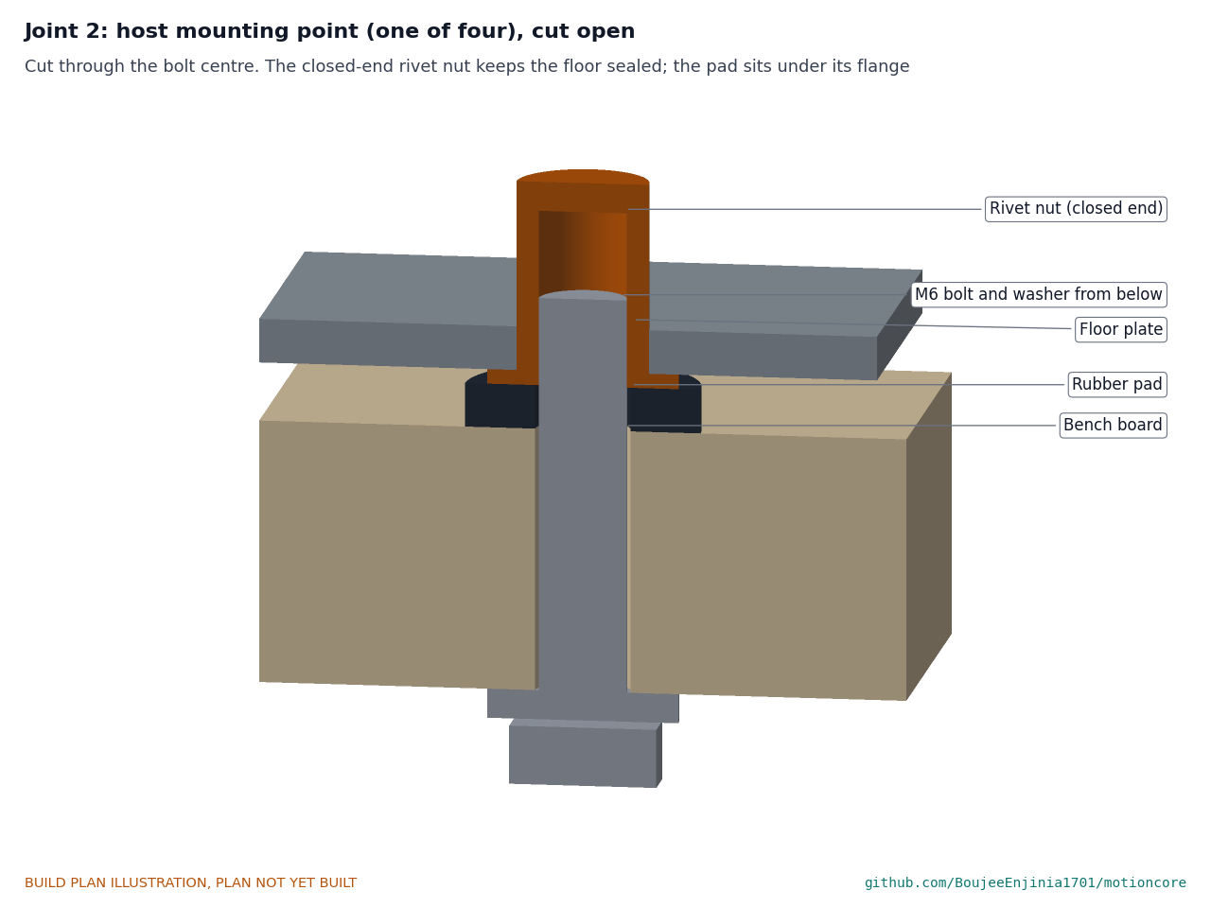
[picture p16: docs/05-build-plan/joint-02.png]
Figure 5. Joint 2: host mounting point


*Figure 5. One of the four mounting points, cut through the bolt: board, rubber pad, rivet nut flange, floor plate and the closed rivet nut body inside.*

**What they are.** Four M6 closed-end steel rivet nuts for a 0.5 to 3 mm grip, and four rubber isolation pads 16 mm across and 3 mm thick with 6.5 mm holes. They are the host mounting interface: four M6 threads on a 180 x 100 mm rectangle.

**How to fit them.** Put each rivet nut in its hole from below, flange against the bottom face, and set it with an M6 rivet nut tool until it pulls tight on the plate and cannot turn. The closed end keeps water out of the module. The pads go between the flange and the host (here the bench board) when the module is mounted (step 8).

**Check before moving on.** Each rivet nut takes an M6 bolt by hand for its full thread and does not spin under a spanner.

### 3.4 Sockets and vent

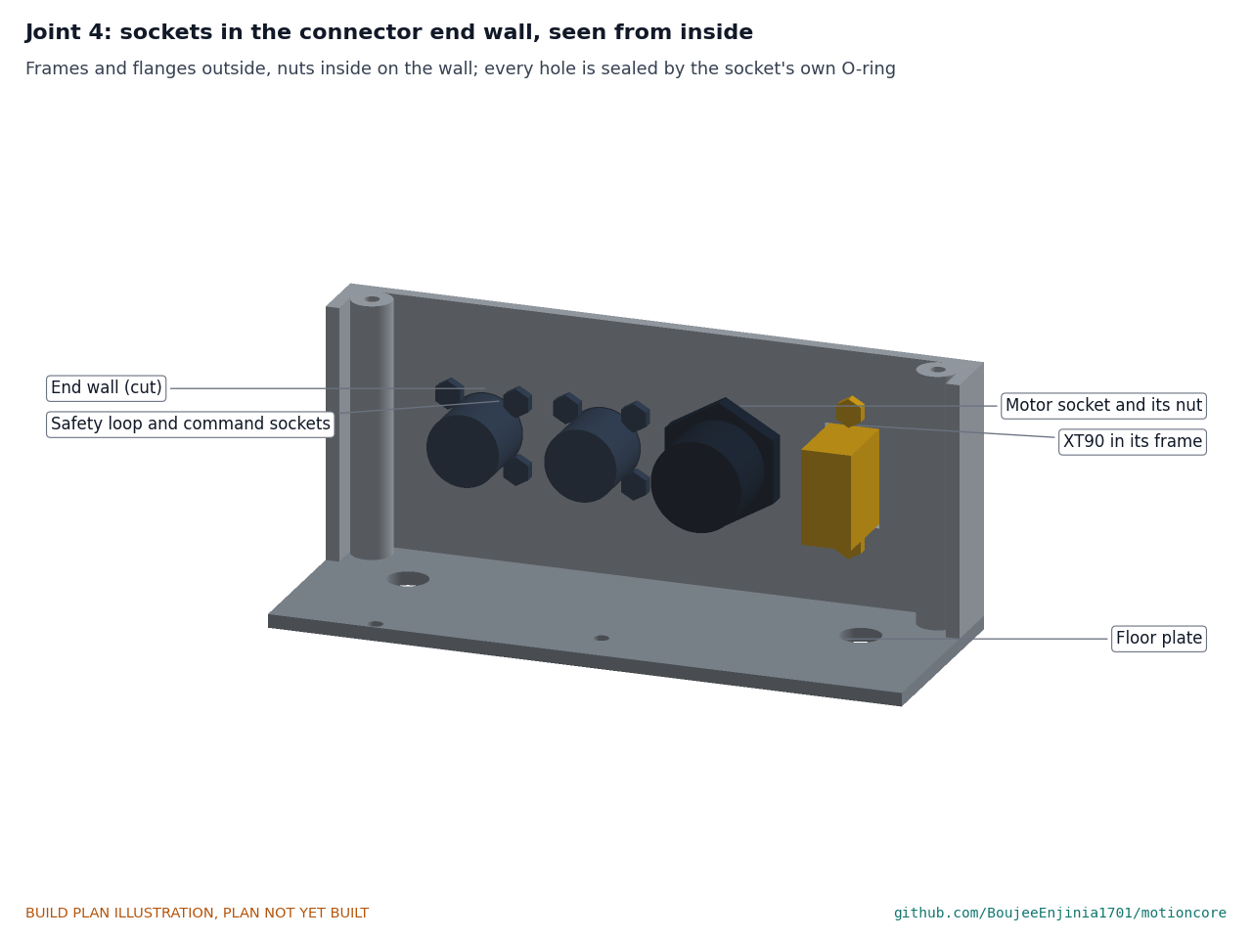
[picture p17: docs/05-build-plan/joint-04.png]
Figure 6. Joint 4: sockets from inside


*Figure 6. The sockets in the connector end wall, seen from inside: frames and flanges outside, nuts inside.*

**What they are.** The power socket (XT90 anti-spark socket in a two-screw panel frame), the 9-pin waterproof motor socket (nut mounted), the safety loop socket (M12 8-pin A-coded) and the command socket (M12 5-pin B-coded, so the two M12 plugs cannot be swapped), both on 20 mm four-screw square flanges; the M8 4-pin speed socket; and a 20 mm adhesive membrane vent.

**How to fit them.** Each socket goes in from outside with its sealing ring between its flange and the wall. The power socket's frame and the M12 flanges are held by M3 screws with nuts inside; the motor socket by its own nut inside, tightened to the maker's torque. The speed socket goes in from outside with its nut inside. Stick the vent patch over the 5 mm hole on a clean, dry wall, pressing it down all round. The power socket is the XT90 for this prototype; it is not sealed, so keep the module dry.

**Check before moving on.** Every socket seats flat on its sealing ring; the M12 coding keys point the same way; nothing inside comes closer than 3 mm to a corner port.

### 3.5 Controller, contactor and precharge and fuse block

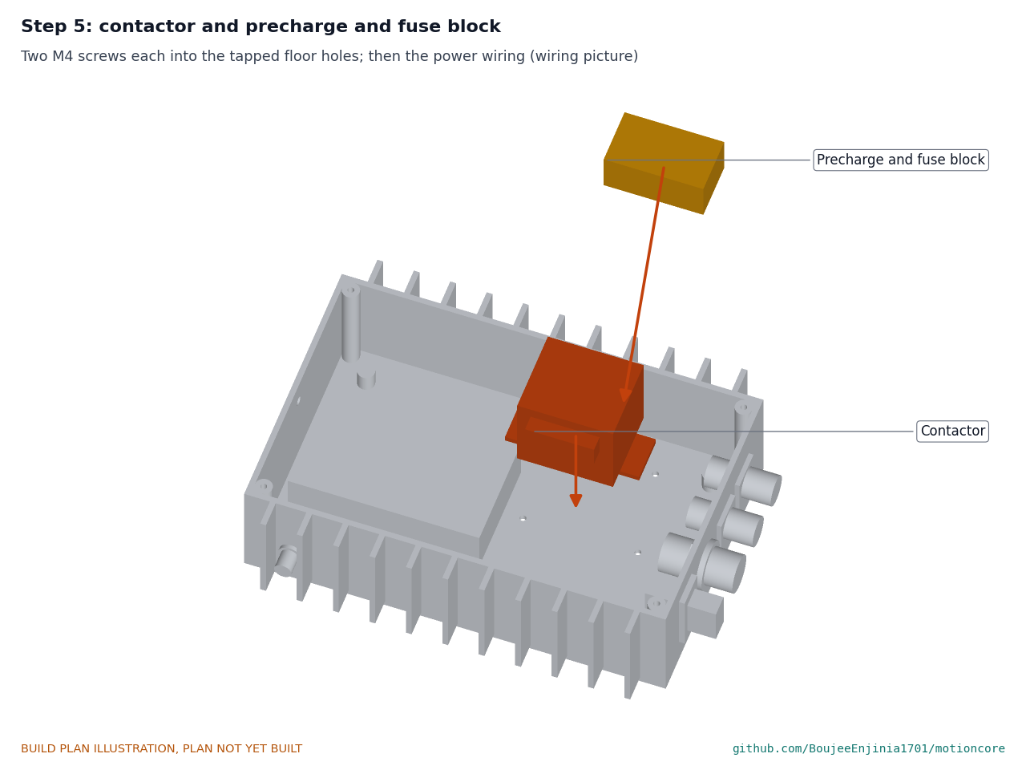
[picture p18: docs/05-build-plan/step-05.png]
Figure 7. Step 5 picture: contactor and fuse block


*Figure 7. The contactor and the precharge and fuse block on the floor plate beside the controller.*

**What they are.** The motor controller is a VESC-class controller with a 75 V power stage, CAN and about 1,000 µF of bus capacitance, with its overvoltage fault set to 66 V. The contactor is a sealed 100 A DC contactor with a 12 V coil and a mounting foot, able to break at least 50 A at 60 V DC and release within 50 ms with a 24 V Zener diode across its coil. The precharge and fuse block is a 100 ohm, 10 W aluminum-clad resistor and a sealed holder for a blade fuse rated 60 V DC or more with at least 1 kA breaking capacity: 20 A for 36 and 48 V packs, 40 A for 24 V packs.

**How to fit them.** The controller sits on a 1 mm thermal pad, trimmed 2 mm inside its base, on four M3 screws into the tapped floor holes. The contactor stands on its foot on two M4 screws. The precharge and fuse block sits on the plain side beside the contactor on two M4 screws. Put a drop of thread sealant on every screw that goes into the floor, and choose lengths that end flush with the floor's bottom face.

**Check before moving on.** Nothing rocks; the controller's base is flat on its pad; the contactor's terminals face the socket side with room for a spanner.

### 3.6 Supervisor carrier board

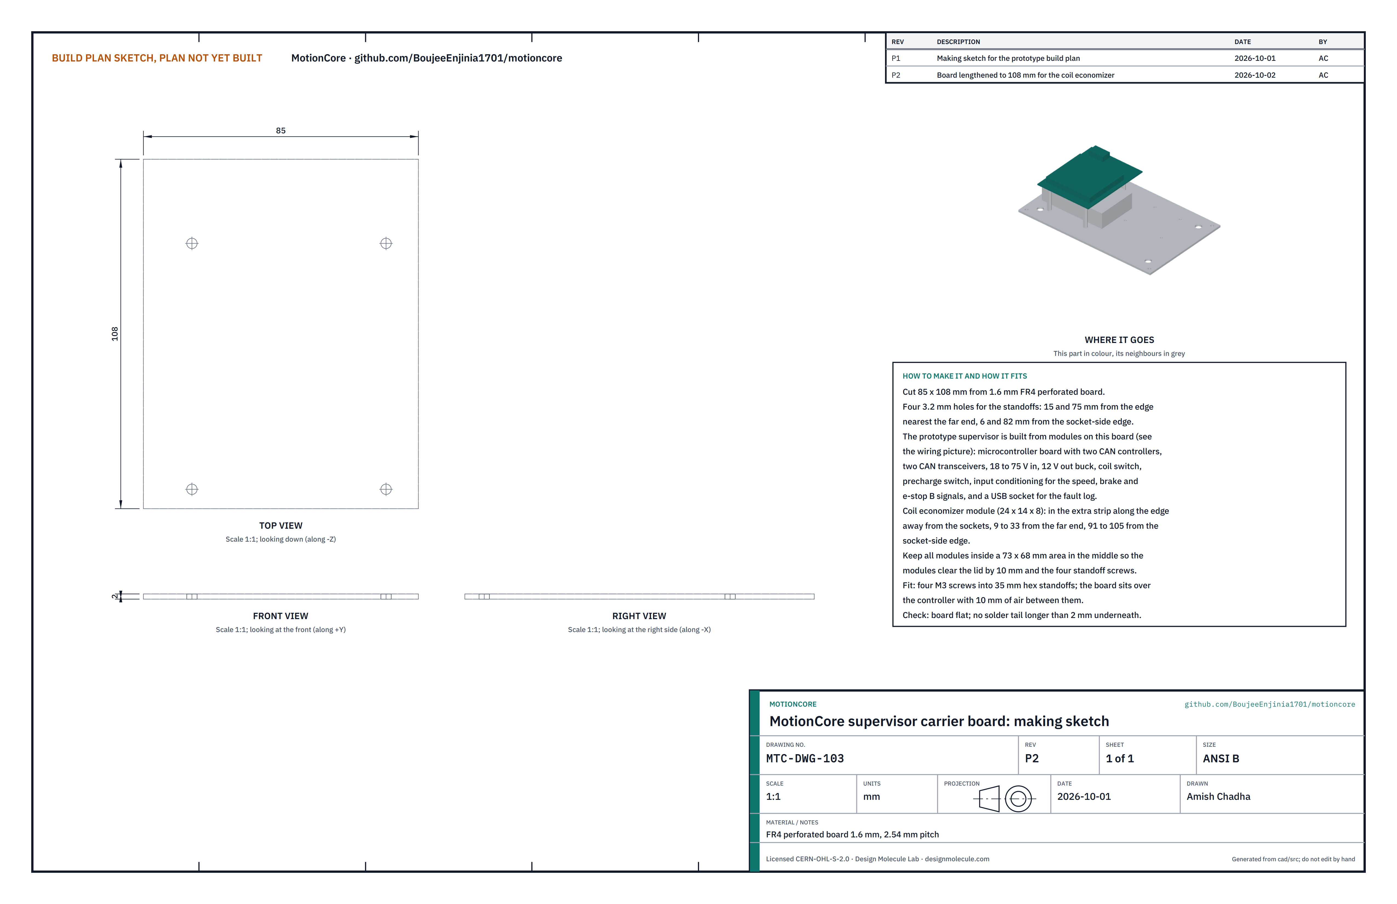
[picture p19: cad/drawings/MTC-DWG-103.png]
Figure 8. Making sketch of the supervisor carrier board


*Figure 8. Supervisor carrier board making sketch (MTC-DWG-103).*

**What it is and what it is made from.** The safety supervisor, built for the prototype from bought modules on a carrier board. FR4 perforated board 1.6 mm thick, 2.54 mm pitch, cut to 85 x 108 mm.

**How to make it.**

1. Cut the board to 85 x 108 mm. Drill four 3.2 mm holes 15 and 75 from the edge nearest the far end, 6 and 82 from the socket-side edge.
2. Lay out the modules of Table 2 inside a 73 x 68 mm area in the middle, so they clear the lid by 10 mm and the four standoff screws.
3. Fix the coil economizer module (24 x 14 x 8 mm) in the extra strip along the edge away from the sockets, 9 to 33 mm from the far-end edge and 91 to 105 mm from the socket-side edge, so it clears the lid by 10 mm and the contactor by more than 50 mm.
4. Fix each module with M2.5 or M3 screws and nylon spacers, or solder its header pins to the board.
5. Wire them as Figure 10 shows, with the signal pins of Table 3.

*Table 2. Modules that make up the prototype supervisor.*

| Module | What to buy |
| --- | --- |
| Microcontroller | STM32G0B1-class board with two CAN controllers and a USB socket for the fault log |
| CAN transceivers | Two 3.3 V CAN transceiver modules: one for the internal bus to the controller (500 kbit/s), one for the external bus to the pack or battery management system (250 kbit/s) |
| Auxiliary supply | Buck converter, 18 to 75 V in, 12 V out, 10 W, for the contactor coil and the logic |
| Coil switch | Logic-level N-channel MOSFET module, at least 2 A and 60 V, in series with the coil loop |
| Coil economizer | 12 V, 1 A contactor coil economizer module: full voltage for 0.5 s, then pulse-width modulated hold at about 1 W; output capacitor 100 µF or less |
| Precharge switch | Logic-level MOSFET module, at least 1 A and 75 V, in series with the precharge resistor |
| Input conditioning | Opto-isolated or resistor-divider inputs for e-stop B, both brake switches and the speed pickup; a 0.8 to 4.2 V analog input for the throttle |

**How it fits the parts next to it.**

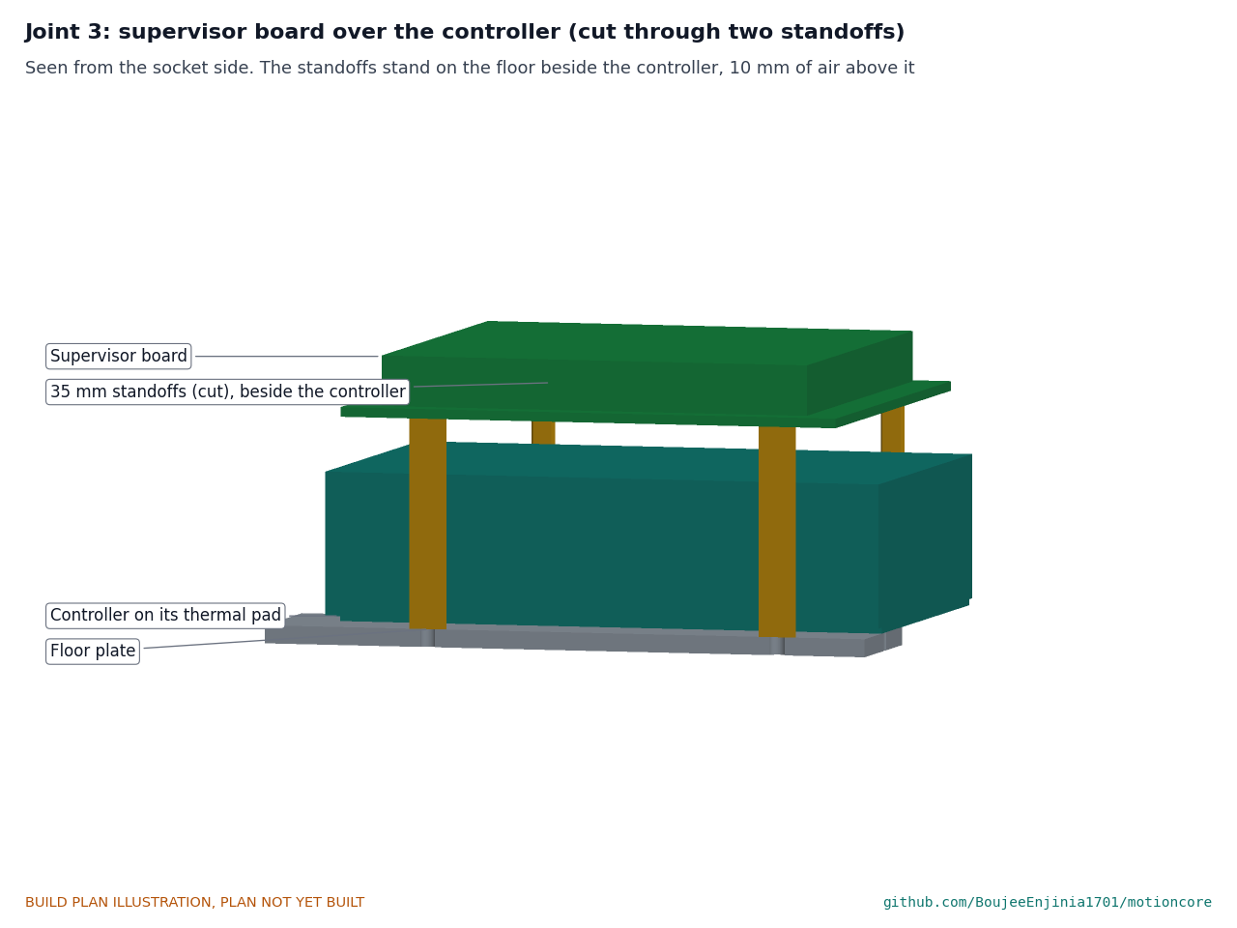
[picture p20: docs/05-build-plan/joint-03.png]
Figure 9. Joint 3: supervisor board over the controller


*Figure 9. The board stands on four 35 mm standoffs beside the controller, with 10 mm of air above the controller.*

The standoffs screw into the floor's tapped holes and the board onto the standoffs with four M3 screws.

**Check before moving on.** The board is flat; no solder tail underneath is longer than 2 mm; with nothing connected, each supply rail reads open to ground.

#### 3.6.1 Wiring inside the module and the connector pins

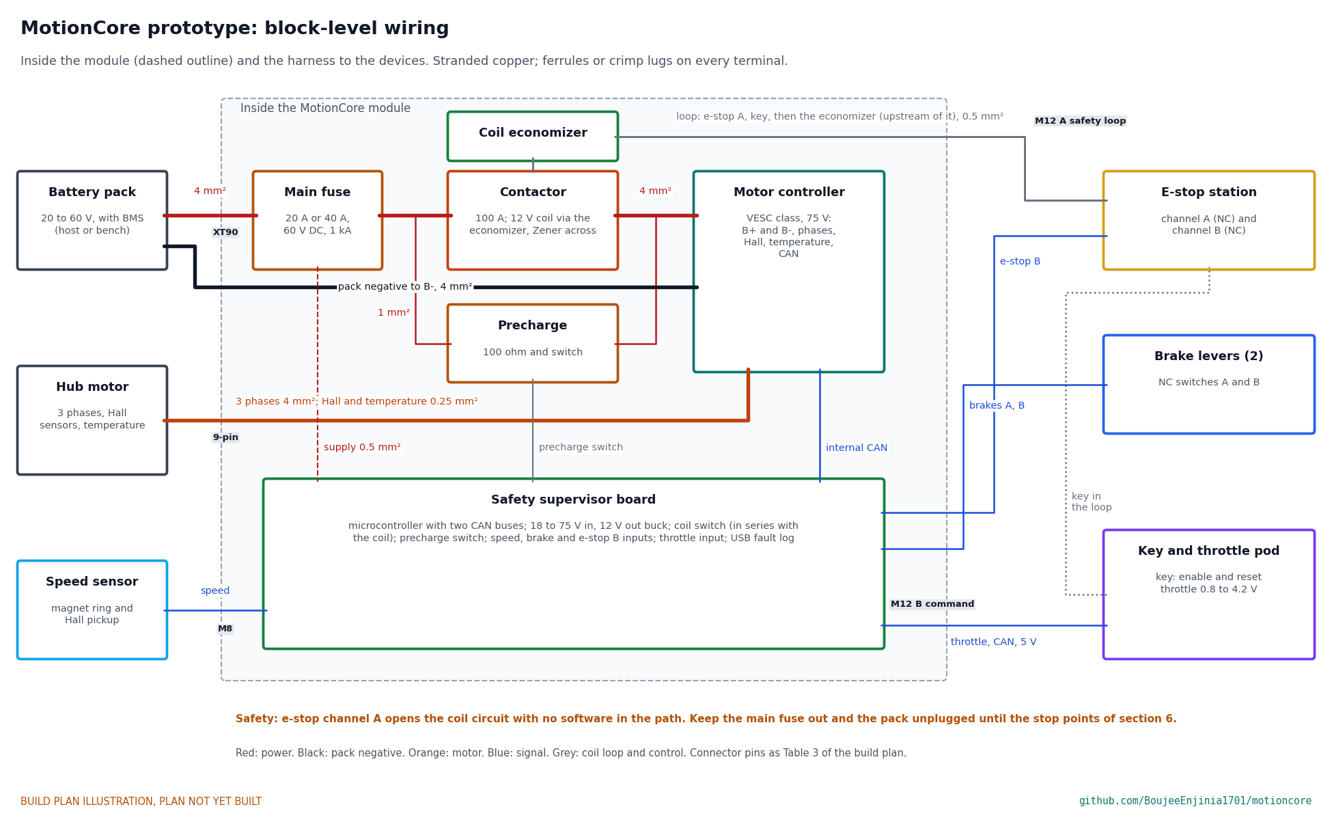
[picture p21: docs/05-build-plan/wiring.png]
Figure 10. Block-level wiring


*Figure 10. Block-level wiring with wire sizes. No circuit board is laid out at this stage; bought modules stand in for the supervisor board.*

Wire it like this, with stranded copper, crimped ring lugs on studs and ferrules on screw terminals:

1. Power socket positive to the main fuse holder, fuse holder to one contactor terminal, the other contactor terminal to the controller's battery positive: 4 mm² (12 AWG).
2. Power socket negative to the controller's battery negative: 4 mm².
3. Precharge resistor and the supervisor's precharge switch in series, across the contactor's two terminals: 1 mm² (18 AWG).
4. The supervisor's auxiliary supply from the fuse side of the contactor and from battery negative: 0.5 mm² (20 AWG).
5. Coil loop: the supervisor's 12 V out to safety loop pin 1; safety loop pin 2 back to the coil economizer's input, so the loop breaks the coil supply upstream of the economizer; the economizer's output to the contactor coil; the coil's other end through the supervisor's coil switch to ground: 0.5 mm². Fit the 24 V Zener diode across the coil, cathode to the positive end.
6. Motor socket to the controller: three phases 4 mm²; Hall sensors, their 5 V and ground, and the motor temperature 0.25 mm² (24 AWG), pin for pin as the motor's maker lists them.
7. Internal CAN between the supervisor and the controller: twisted pair 0.25 mm², with a 120 ohm terminator at each end.
8. Safety loop pins 3, 4, 5 and 7, command pins 1 to 5 and speed pins 1, 3 and 4 to the supervisor: 0.25 mm², as Table 3.

*Table 3. Connector pins.*

| Socket | Pin | Line |
| --- | --- | --- |
| Safety loop (M12, 8-pin A) | 1 | Loop supply, 12 V out to e-stop channel A |
| | 2 | Loop return, after e-stop channel A and the key, to the contactor coil |
| | 3 | E-stop channel B (to ground when the e-stop is not pressed) |
| | 4 | Brake switch A (to ground when the lever is released) |
| | 5 | Brake switch B (to ground when the lever is released) |
| | 6 | Brake coil output, 12 V, for a host's spring-applied brake; live only while the loop is closed (not used on the bench) |
| | 7 | Ground |
| | 8 | Not connected |
| Command (M12, 5-pin B) | 1 | +5 V for the throttle |
| | 2 | Throttle signal, 0.8 to 4.2 V |
| | 3 | Ground |
| | 4 | CAN high, external bus |
| | 5 | CAN low, external bus |
| Speed (M8, 4-pin A) | 1 | +5 V |
| | 3 | Ground |
| | 4 | Speed pulses |
| | 2 | Not connected |

**Check before moving on.** Every wire continues end to end and is labelled; with the fuse out, the power socket's two pins read open to each other; the coil loop reads closed through the coil only when pins 1 and 2 are bridged.

### 3.7 Lid and lid gasket

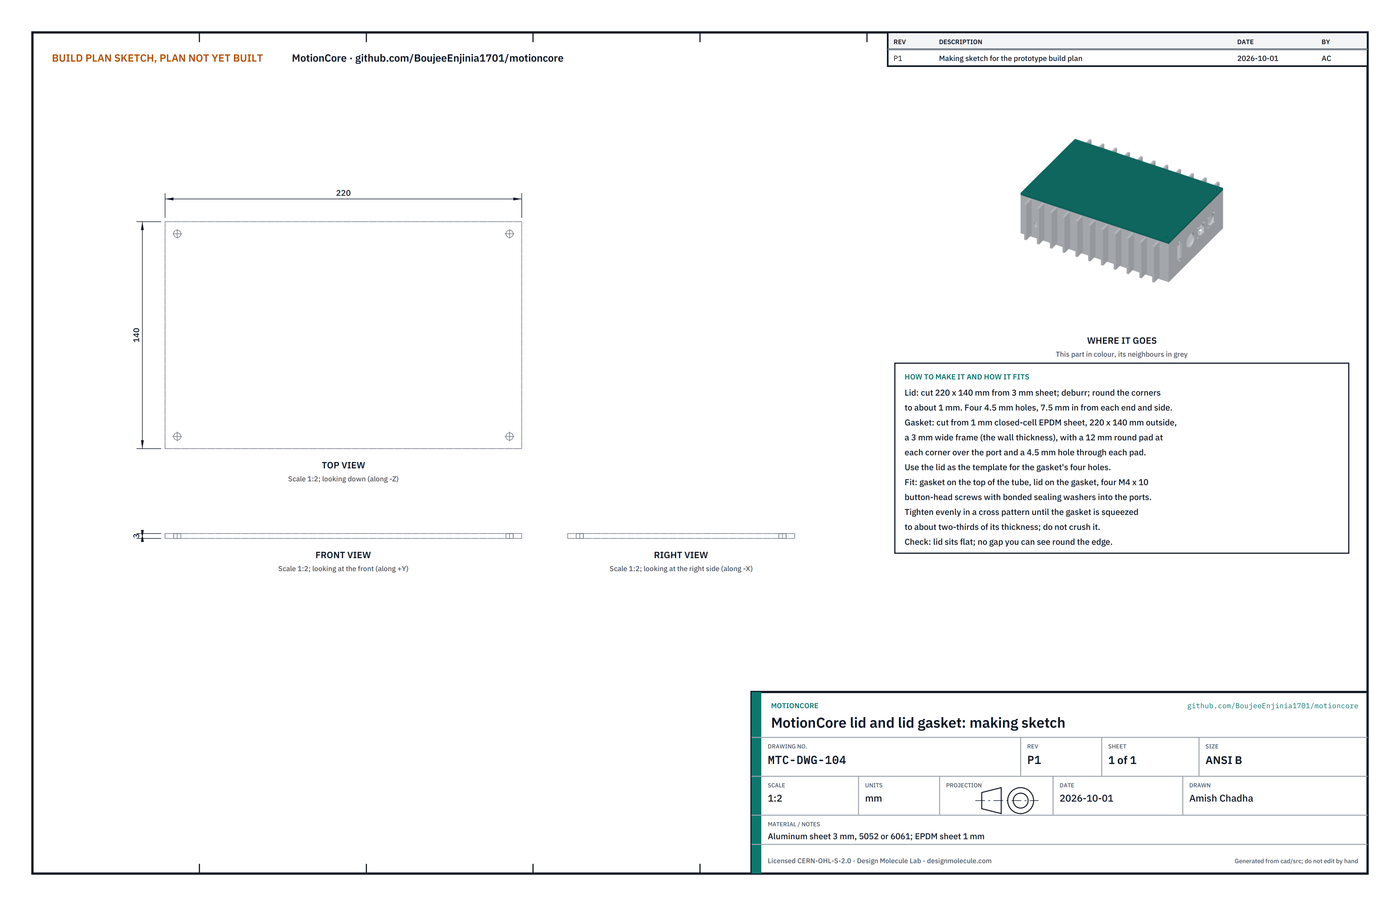
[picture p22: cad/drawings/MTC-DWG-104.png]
Figure 11. Making sketch of the lid and gasket


*Figure 11. Lid and gasket making sketch (MTC-DWG-104).*

**What they are and what they are made from.** The lid closes the top of the tube and is part of the heat sink. Aluminum sheet 3 mm, 5052 or 6061, cut to 220 x 140 mm. The gasket seals it: closed-cell EPDM sheet 1 mm thick.

**How to make them.**

1. Lid: cut 220 x 140 mm; deburr; round the corners to about 1 mm. Drill four 4.5 mm holes, 7.5 in from each end and each side.
2. Gasket: cut a frame 220 x 140 mm outside and 3 mm wide, with a 12 mm round pad at each corner over the port; punch a 4.5 mm hole through each pad, using the lid as the template.

**How it fits the parts next to it.**

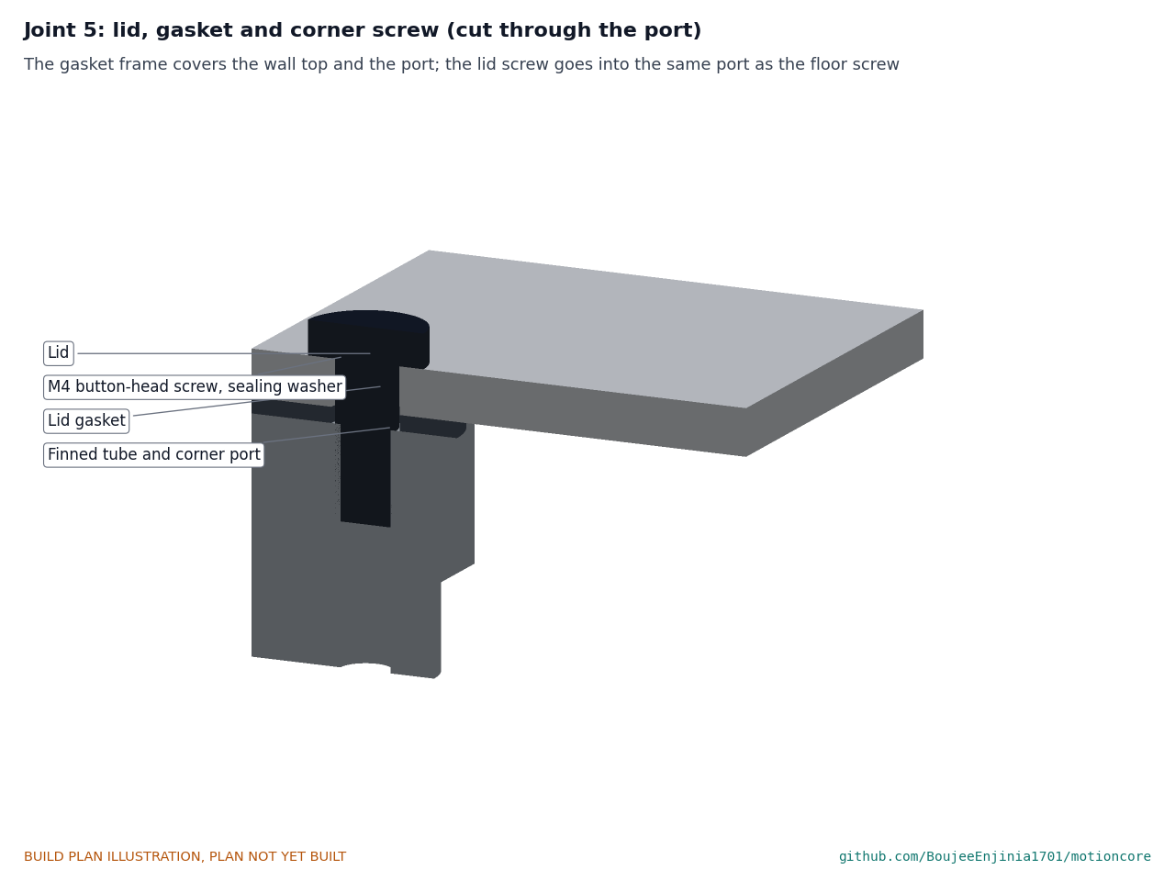
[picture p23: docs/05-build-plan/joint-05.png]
Figure 12. Joint 5: lid corner


*Figure 12. Lid, gasket and corner screw, cut through the port.*

The gasket lies on the top of the walls and ports; the lid lies on the gasket; four M4 x 10 stainless button-head screws with bonded sealing washers go into the ports. Tighten them evenly in a cross pattern until the gasket is squeezed to about two-thirds of its thickness.

**Check before moving on.** The lid sits flat with no gap you can see round the edge; the gasket is not pinched out at any point.

### 3.8 Bench board

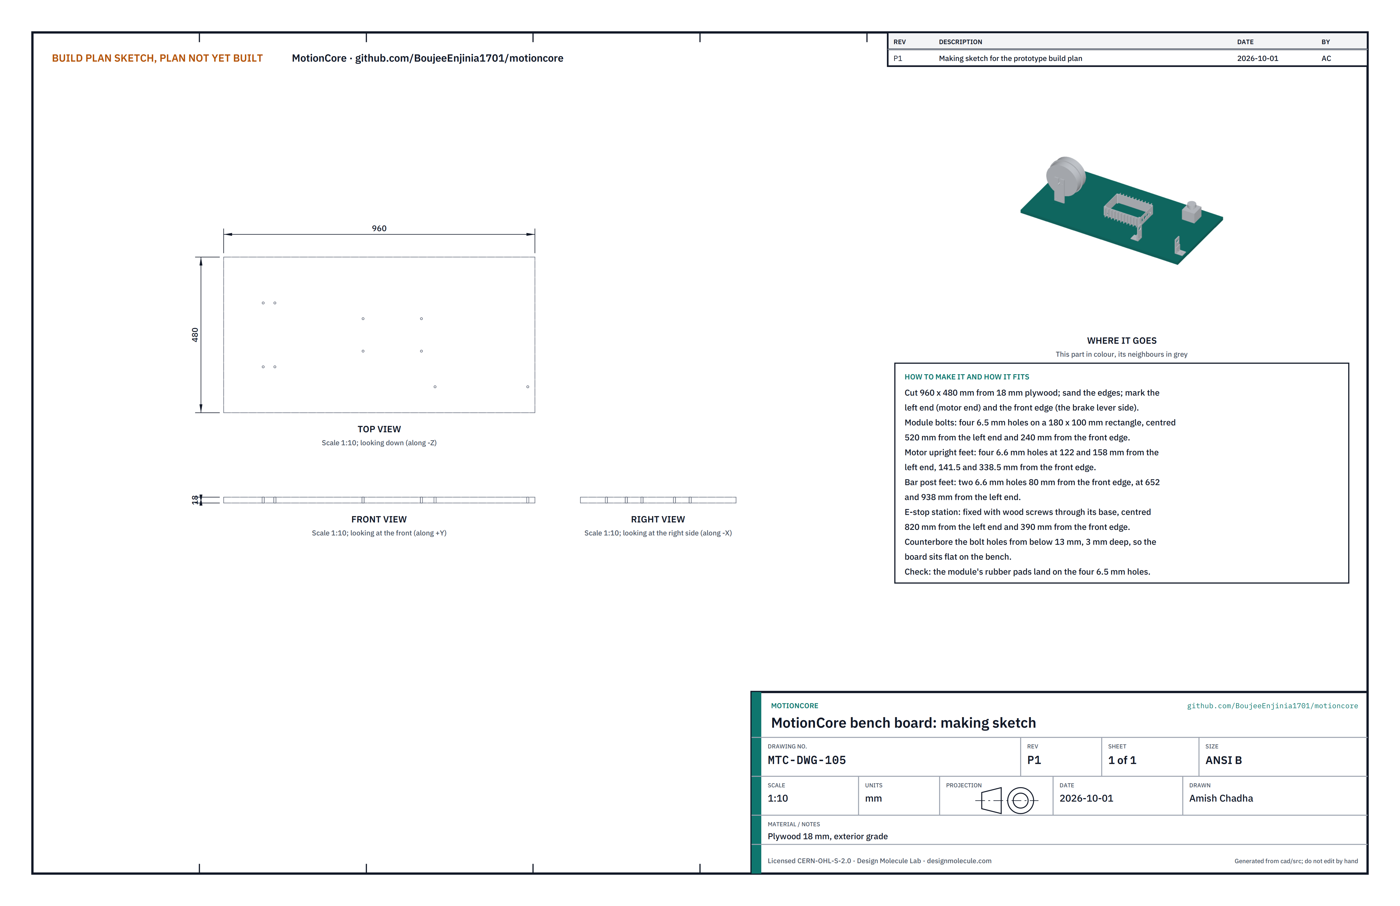
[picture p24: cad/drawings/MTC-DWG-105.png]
Figure 13. Making sketch of the bench board


*Figure 13. Bench board making sketch (MTC-DWG-105).*

**What it is and what it is made from.** The base of the bench rig, standing in for a host vehicle. Exterior-grade plywood 18 mm thick, cut to 960 x 480 mm. The motor end is the left end; the front edge is the side the brake levers face.

**How to make it.**

1. Cut 960 x 480 mm; sand the edges and corners.
2. Module bolt holes: four 6.5 mm holes on a 180 x 100 mm rectangle, centred 520 from the left end and 240 from the front edge.
3. Motor upright feet: four 6.6 mm holes at 122 and 158 from the left end, 141.5 and 338.5 from the front edge.
4. Bar post feet: two 6.6 mm holes 80 from the front edge, at 652 and 938 from the left end.
5. Counterbore every bolt hole from below, 13 mm across and 3 mm deep, so the bolt heads keep the board flat on the bench.
6. Mark the e-stop station's place, centred 820 from the left end and 390 from the front edge.

**How it fits the parts next to it.** It lies flat on a sturdy bench, clamped at both ends. Everything else bolts or screws to it.

**Check before moving on.** Hold the module with its pads on the board: the four rivet nuts sit over the four 6.5 mm holes.

### 3.9 Motor uprights (make 2)

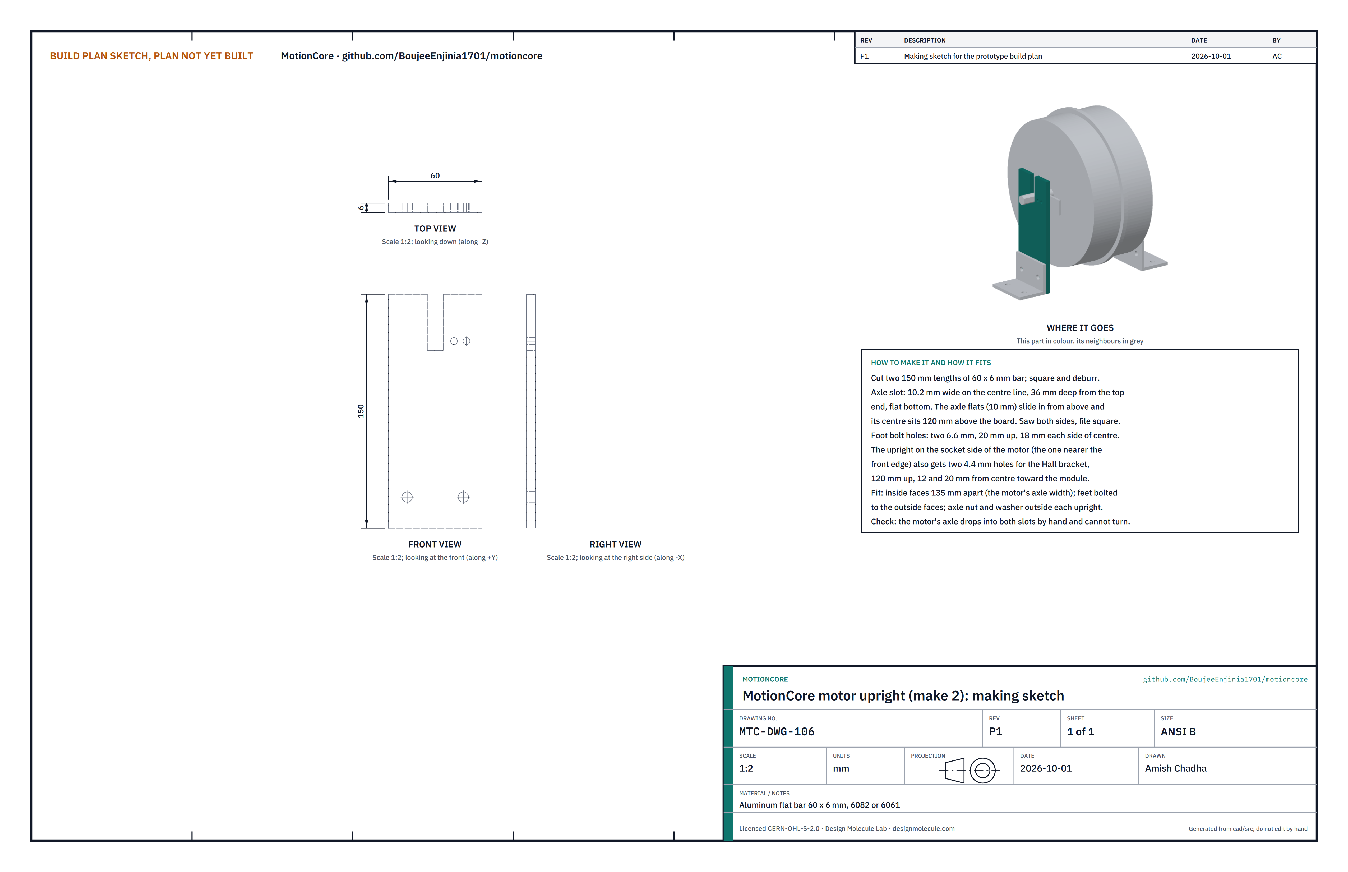
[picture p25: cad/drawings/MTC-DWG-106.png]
Figure 14. Making sketch of the motor upright


*Figure 14. Motor upright making sketch (MTC-DWG-106).*

**What it is and what it is made from.** The pair of uprights that hold the hub motor by its axle with the wheel clear of the board. Aluminum flat bar 60 x 6 mm, 6082 or 6061.

**How to make it.**

1. Cut two 150 mm lengths; square and deburr.
2. Axle slot: 10.2 wide on the centre line, 36 deep from the top end, with a flat bottom. Saw both sides and file square. The axle's 10 mm flats slide in from above and its centre sits 120 above the board.
3. Foot bolt holes: two 6.6 mm holes 20 up from the bottom end, 18 each side of the centre line.
4. On one upright only (the one on the front-edge side, which carries the speed pickup), drill two 4.4 mm holes 120 up, 12 and 20 from the centre line toward the module.

**How it fits the parts next to it.**

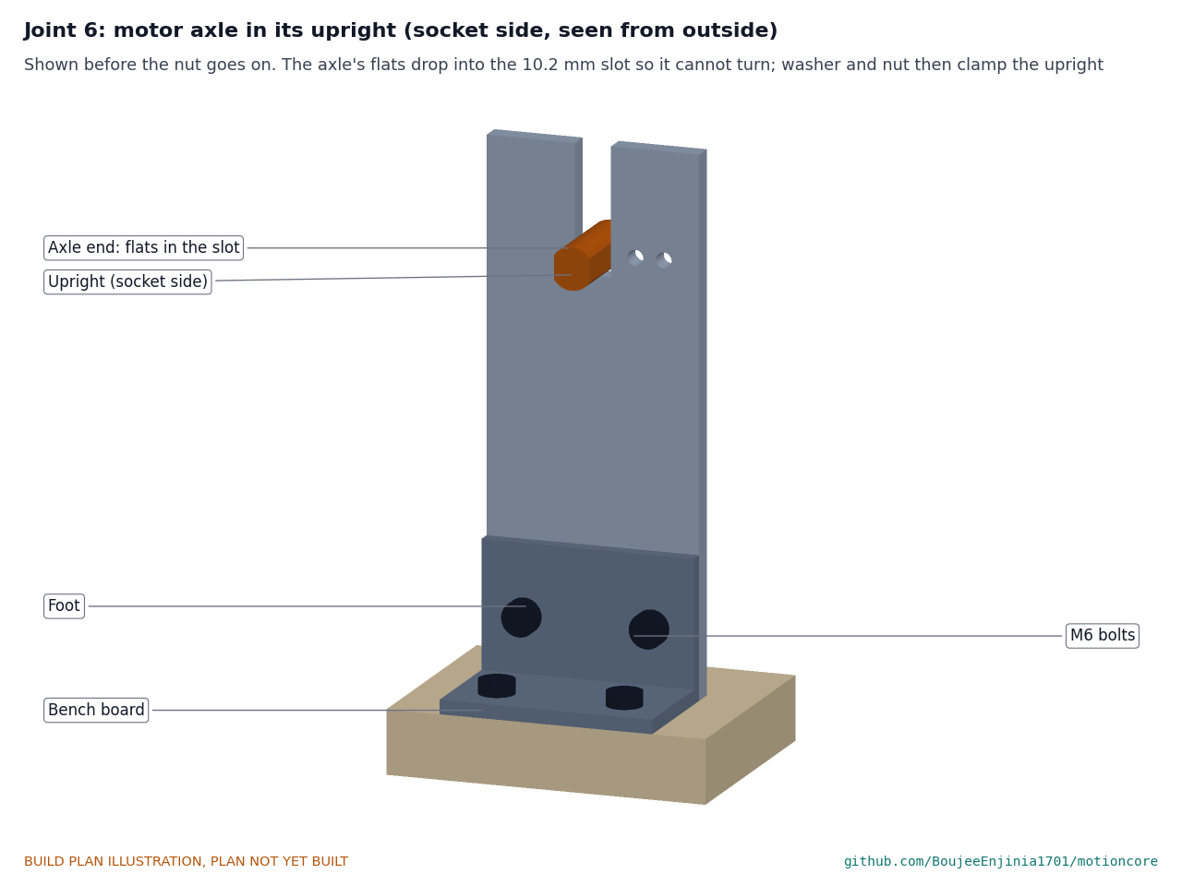
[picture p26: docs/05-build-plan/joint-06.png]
Figure 15. Joint 6: axle in its upright


*Figure 15. The axle end in the slot, before the washer and nut go on.*

The uprights stand on the board with their inside faces 135 apart, the motor's axle width; check yours and set the gap to suit. A foot bolts to the outside face of each. The axle's flats drop into both slots so the axle cannot turn, and a washer and the axle nut on the outside clamp each upright.

**Check before moving on.** With the motor in place the axle drops into both slots by hand, cannot turn, and the shell is about 19 mm above the board.

### 3.10 Upright feet (make 4: two 60 mm, two 40 mm)

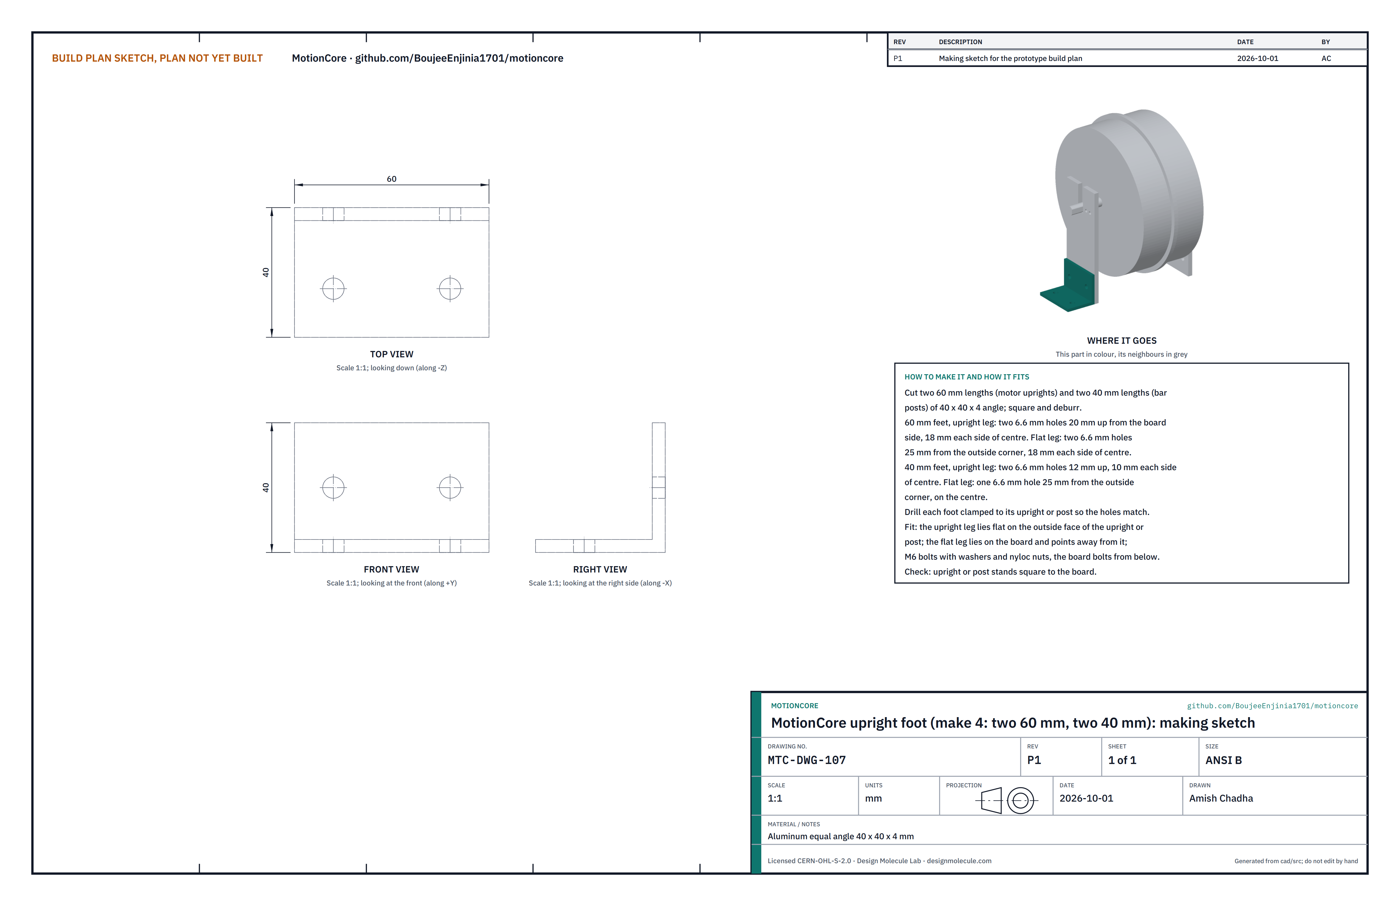
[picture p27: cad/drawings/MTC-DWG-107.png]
Figure 16. Making sketch of the upright foot


*Figure 16. Upright foot making sketch (MTC-DWG-107).*

**What it is and what it is made from.** Short angles that fix the motor uprights and the bar posts to the board. Aluminum equal angle 40 x 40 x 4 mm.

**How to make it.**

1. Cut two 60 mm lengths (motor uprights) and two 40 mm lengths (bar posts); square and deburr.
2. 60 mm feet: upright leg, two 6.6 mm holes 20 up from the board side, 18 each side of centre; flat leg, two 6.6 mm holes 25 from the outside corner, 18 each side of centre.
3. 40 mm feet: upright leg, two 6.6 mm holes 12 up, 10 each side of centre; flat leg, one 6.6 mm hole 25 from the outside corner, on the centre.
4. Drill each foot's upright leg clamped to its upright or post so the holes match.

**How it fits the parts next to it.** The upright leg lies flat on the outside face of its upright or post, held by M6 bolts with washers and nyloc nuts; the flat leg lies on the board, pointing away from the upright, held by M6 bolts from below.

**Check before moving on.** The upright or post stands square to the board when the bolts are tight.

### 3.11 Speed sensor ring

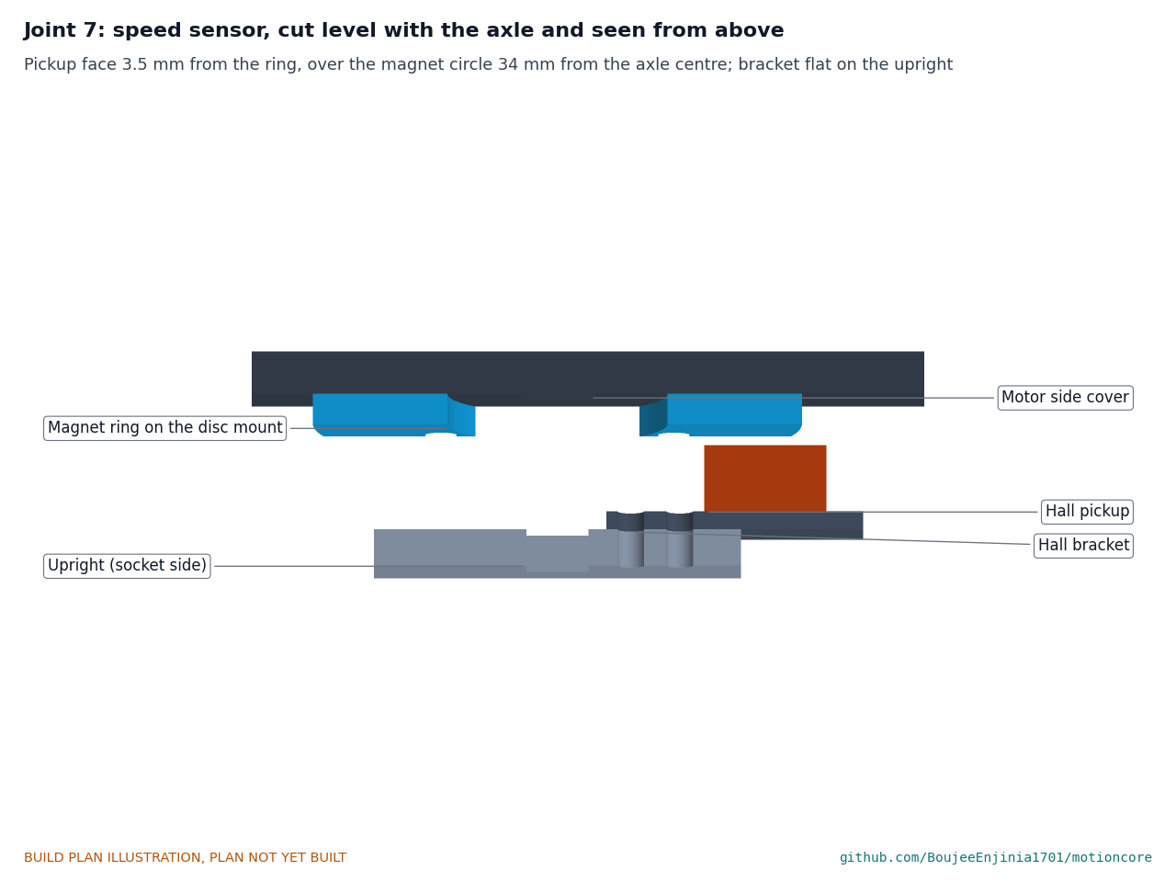
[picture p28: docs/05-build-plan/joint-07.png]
Figure 17. Joint 7: speed sensor


*Figure 17. Cut level with the axle and seen from above: side cover, ring, 3.5 mm gap, pickup, bracket, upright.*

**What it is.** An eight-magnet ring 80 mm across with six 5.5 mm holes on a 44 mm circle, which bolts to the reference motor's six-bolt disc mount, and a sealed Hall pickup with a lead and an M8 plug.

**How to fit it.** Six M5 screws with medium threadlocker into the disc mount, on the side of the motor that faces the front-edge upright.

**Check before moving on.** The ring runs true within 0.5 mm when the wheel is turned by hand.

### 3.12 Hall pickup bracket

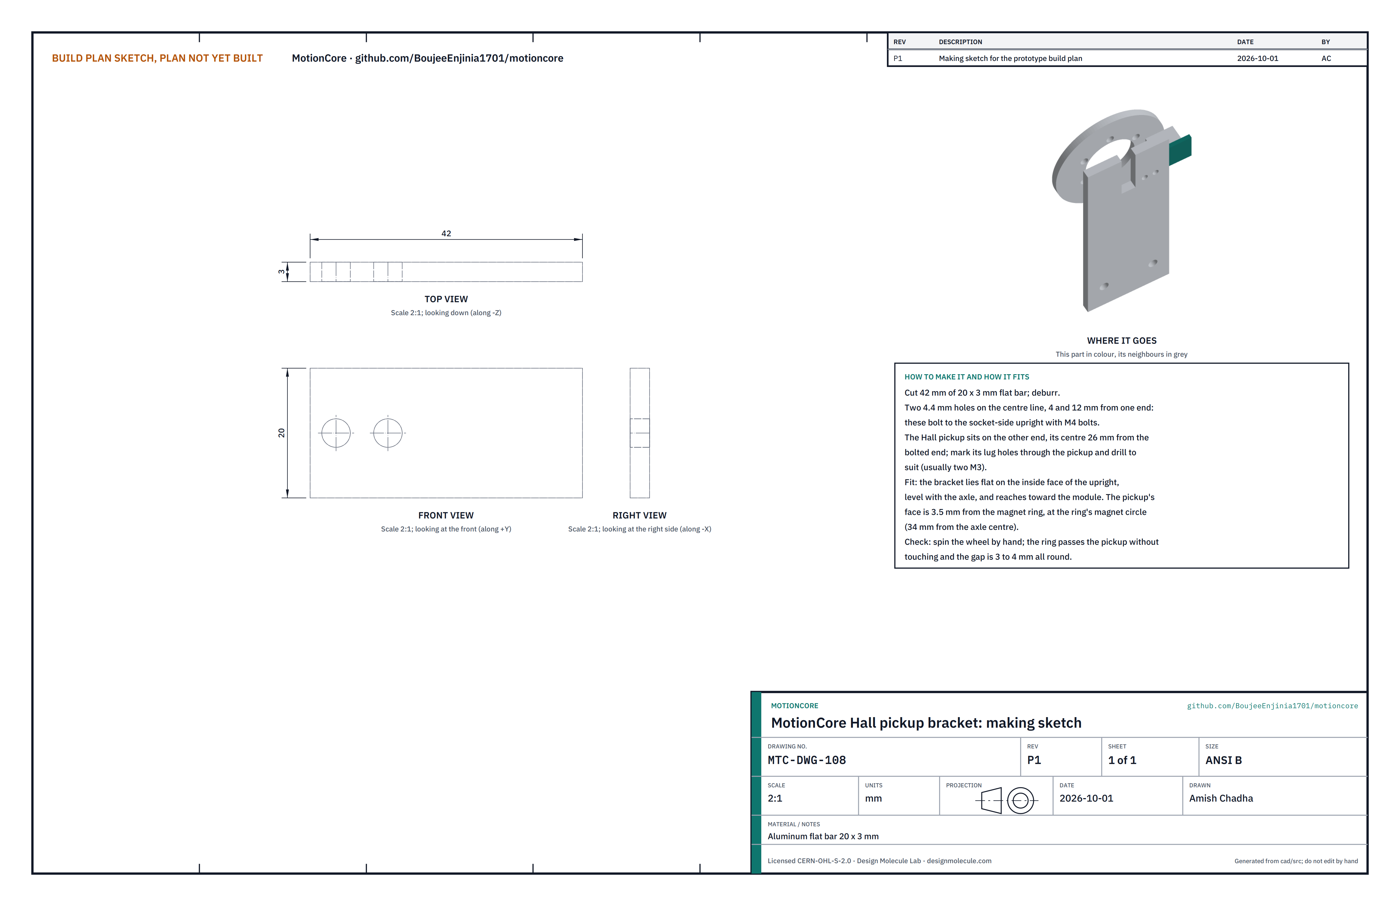
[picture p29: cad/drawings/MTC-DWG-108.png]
Figure 18. Making sketch of the Hall pickup bracket


*Figure 18. Hall pickup bracket making sketch (MTC-DWG-108).*

**What it is and what it is made from.** A short strip that holds the speed sensor's pickup facing the magnet ring. Aluminum flat bar 20 x 3 mm.

**How to make it.**

1. Cut 42 mm; deburr.
2. Drill two 4.4 mm holes on the centre line, 4 and 12 from one end.
3. Hold the pickup on the other end with its centre 26 from the drilled end; mark its lug holes through it and drill to suit (usually two M3).

**How it fits the parts next to it.** The bracket lies flat on the inside face of the front-edge upright, level with the axle, reaching toward the module, on two M4 bolts through the upright. The pickup's face then sits 3.5 from the magnet ring, over the ring's magnet circle 34 from the axle centre (Figure 17).

**Check before moving on.** Turn the wheel by hand: the ring passes the pickup without touching, with a gap of 3 to 4 all round.

### 3.13 Bar posts (make 2)

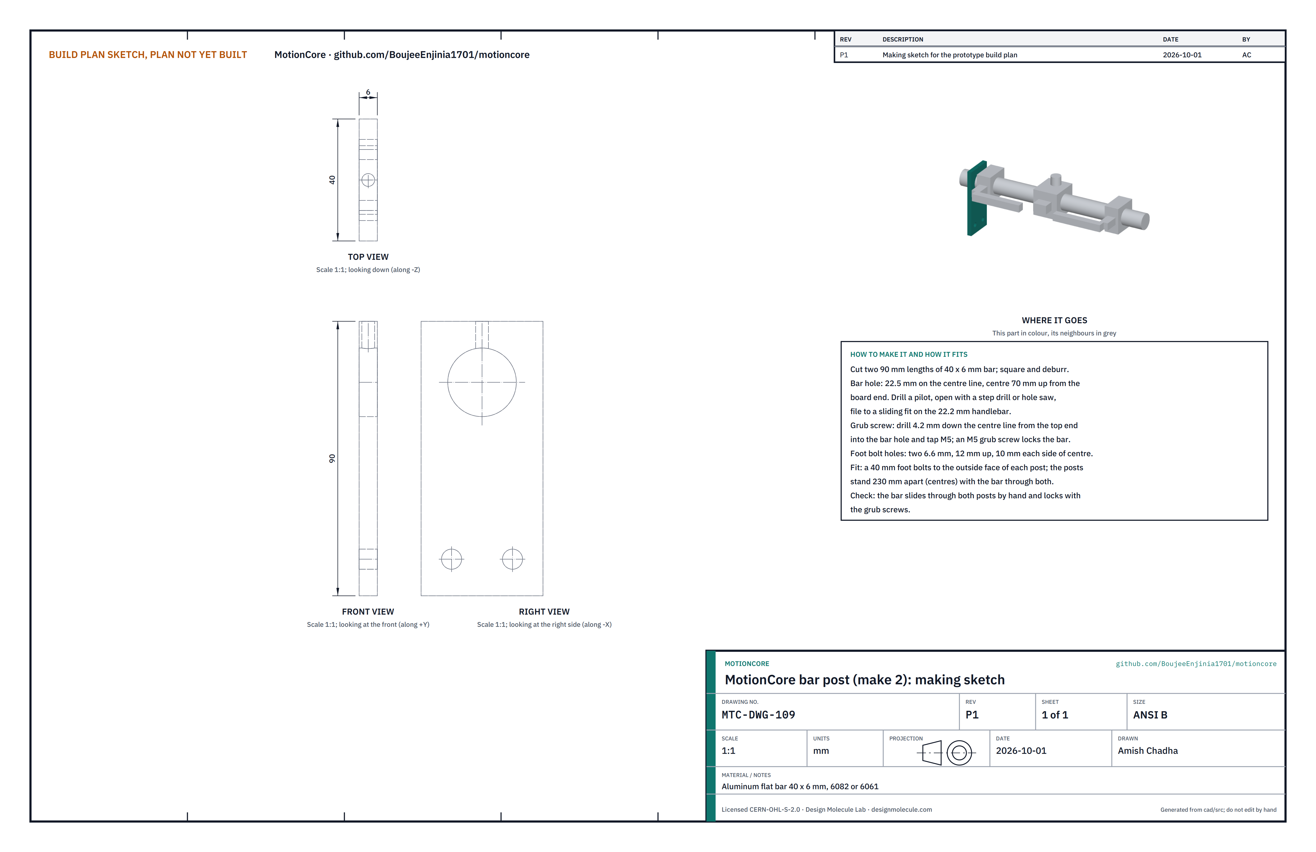
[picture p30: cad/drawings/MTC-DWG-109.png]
Figure 19. Making sketch of the bar post


*Figure 19. Bar post making sketch (MTC-DWG-109).*

**What it is and what it is made from.** Two posts that hold the handlebar stub 70 above the board. Aluminum flat bar 40 x 6 mm, 6082 or 6061.

**How to make it.**

1. Cut two 90 mm lengths; square and deburr.
2. Bar hole: 22.5 mm on the centre line, its centre 70 up from the bottom end. Drill a pilot, open out with a step drill or hole saw, and file to a sliding fit on the handlebar.
3. Grub screw: drill 4.2 mm down the centre line from the top end into the bar hole and tap M5.
4. Foot bolt holes: two 6.6 mm holes 12 up, 10 each side of centre.

**How it fits the parts next to it.** A 40 mm foot bolts to the outside face of each post. The posts stand 230 apart (centres) along the front edge with the bar through both, and an M5 grub screw in each locks the bar.

**Check before moving on.** The bar slides through both posts by hand and locks with the grub screws.

### 3.14 Handlebar stub

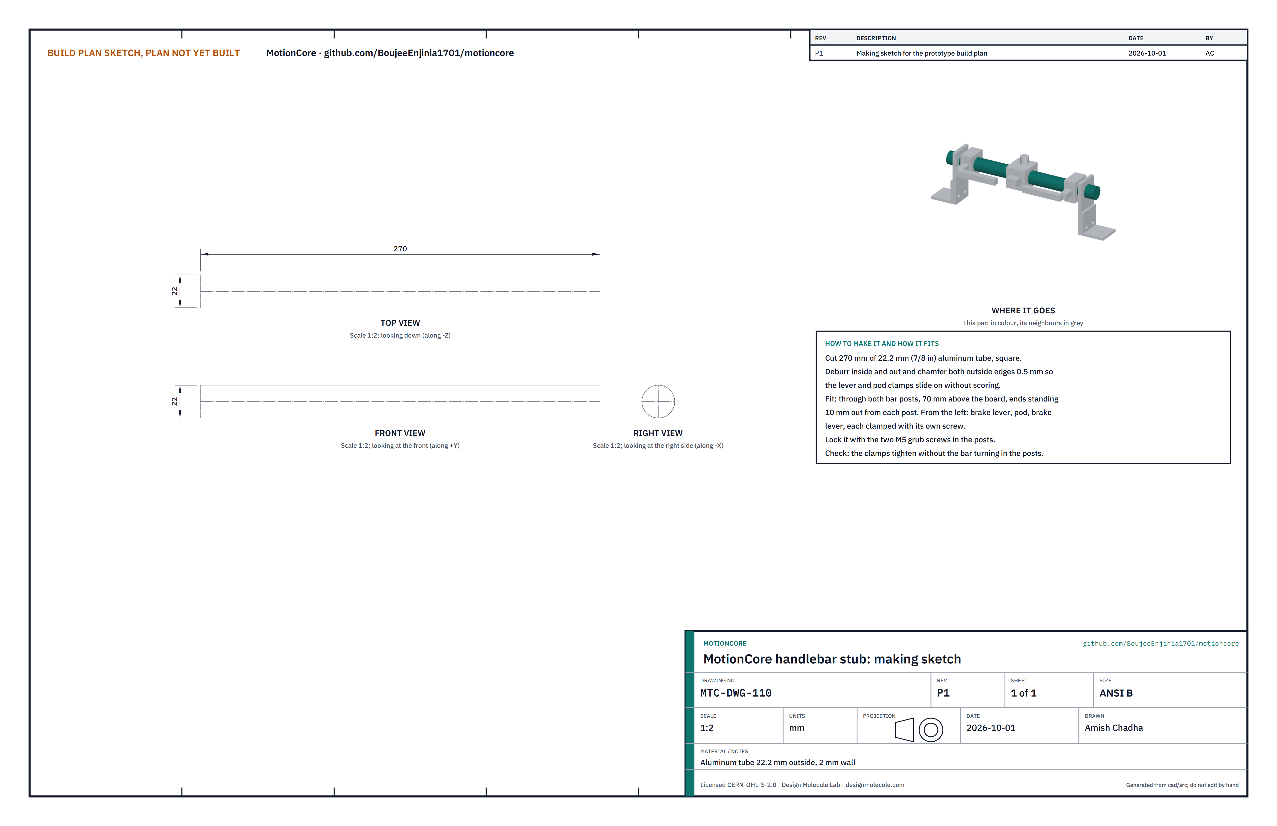
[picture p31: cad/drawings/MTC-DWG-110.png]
Figure 20. Making sketch of the handlebar stub


*Figure 20. Handlebar stub making sketch (MTC-DWG-110).*

**What it is and what it is made from.** A short handlebar for the brake levers and the key and throttle pod, standing in for a host's controls. Aluminum tube 22.2 mm (7/8 in) outside, 2 mm wall, cut to 270 mm.

**How to make it.** Cut square; deburr inside and out; chamfer both outside edges 0.5 mm so the clamps slide on without scoring.

**How it fits the parts next to it.**

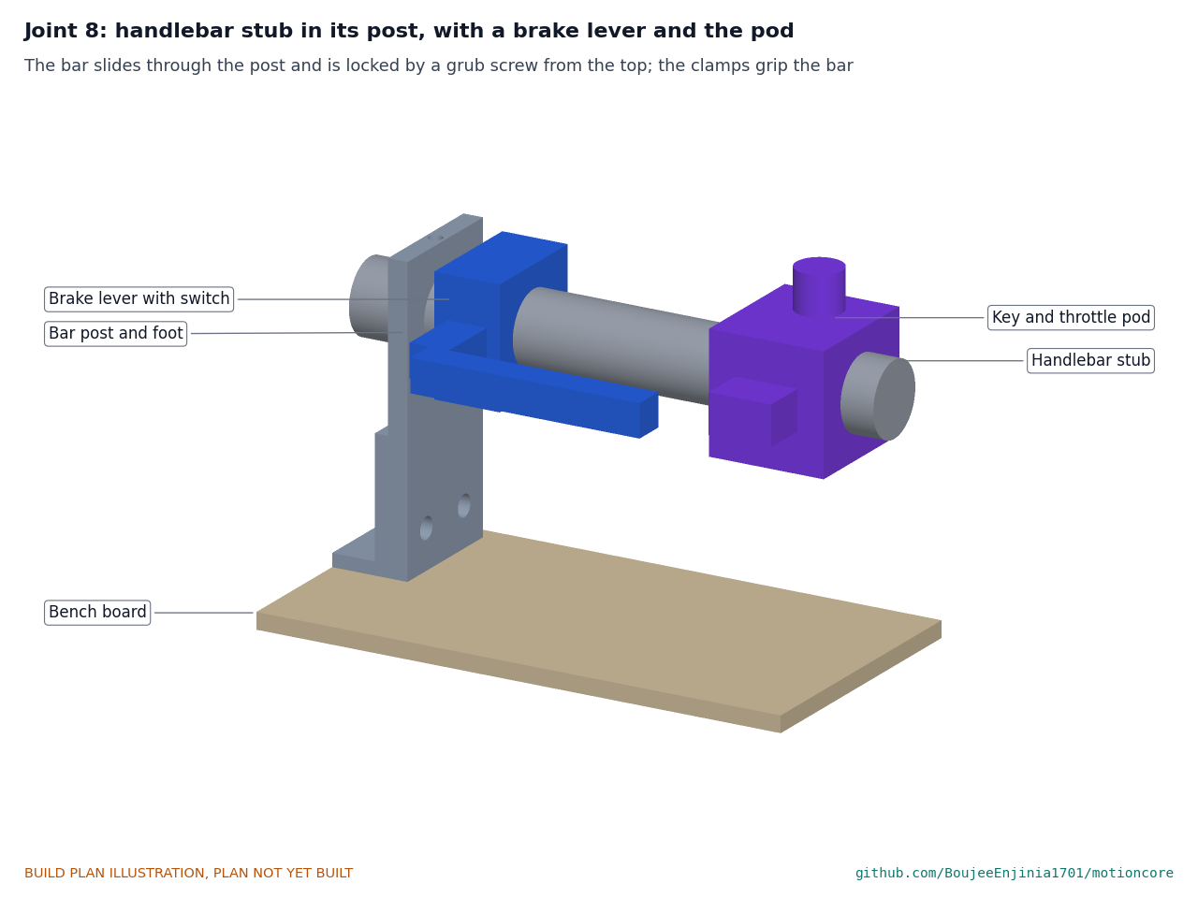
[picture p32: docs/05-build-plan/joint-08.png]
Figure 21. Joint 8: handlebar, post, lever and pod


*Figure 21. The bar slides through the post and is locked from the top; the lever and pod clamp the bar.*

It passes through both posts, 70 above the board, its ends 10 out from each post. From the left: brake lever, pod, brake lever, each clamped with its own screw.

**Check before moving on.** The clamps tighten without the bar turning in the posts.

### 3.15 Harness

**What it is.** Four made-up leads with keyed waterproof plugs, built to Figure 10 and Table 3: the motor lead (supplied with the motor, plugged straight in); the safety loop lead from its M12 plug to the e-stop station, with a branch from the station to both brake levers and the key; the command lead from its M12 plug to the throttle in the pod (and the external CAN pair, left capped on the bench); and the speed lead from the pickup to its M8 plug. Use shielded pairs for the signals, spiral wrap, and adhesive cable clips to hold every lead to the board.

**How to make it.** Cut each lead to length on the board with 100 mm spare. Crimp the M12 and M8 field plugs to the pins of Table 3. In the e-stop station, wire channel A in series with the key so the loop runs pin 1, channel A, key, pin 2; wire channel B and the brake switches between their pins and ground (pin 7).

**Check before moving on.** With a meter at the plugs: pins 1 and 2 of the safety loop read closed with the e-stop up and the key on, open when the e-stop is pressed or the key is off; pins 3, 4 and 5 each read to pin 7 and open when their switch acts; the throttle reads about 0.8 V and 4.2 V at its ends when fed 5 V.

### 3.16 Bought components

Buy to specification, not brand. Line numbers are those of the bill of materials.

- **Reference hub motor (line 1).** 250 W geared brushless hub motor, 36 or 48 V winding, Hall sensors and temperature sensor, 9-pin waterproof plug, freewheel, 10 mm axle flats, axle width about 135 mm, six-bolt disc mount.
- **Motor controller (line 2), contactor (line 4), precharge and fuse block (line 5).** As section 3.5.
- **Finned enclosure extrusion (line 6).** As section 3.2; 6061 plate for the floor; thermally conductive silicone sealant (about 1 W/m·K).
- **Sockets and vent (line 8).** As section 3.4.
- **E-stop station (line 9).** 22 mm red mushroom-head pushbutton on a yellow enclosure, twist release, two normally closed contact blocks with positive opening.
- **Brake levers (line 10).** Two e-bike levers for 22.2 mm bars with built-in normally closed cut-off switches.
- **Key and throttle pod (line 11).** Two-position key switch and hall-effect thumb throttle (0.8 to 4.2 V) in one pod for a 22.2 mm bar.
- **Speed sensor (line 12).** As section 3.14.
- **Fixings (line 14).** Four M6 closed-end rivet nuts; four 16 x 3 mm rubber pads; four 35 mm M3 hex standoffs; four M4 x 8 countersunk screws (floor); four M4 x 10 button-head screws with bonded sealing washers (lid); M3 and M4 stainless screws and nuts; 1 mm thermal pad; medium thread sealant; cable ties and labels.
- **Bench rig fixings (line 15).** Four M6 x 30 bolts with washers (module); M6 x 16 bolts with washers and nyloc nuts (feet); two M4 x 12 bolts with nuts (Hall bracket); two M5 grub screws; wood screws for the e-stop station.

## 4. Putting it together

In each picture the parts already fitted are grey and the part being fitted is in colour, with an arrow showing the way it goes in.

### Step 1: rivet nuts into the floor plate

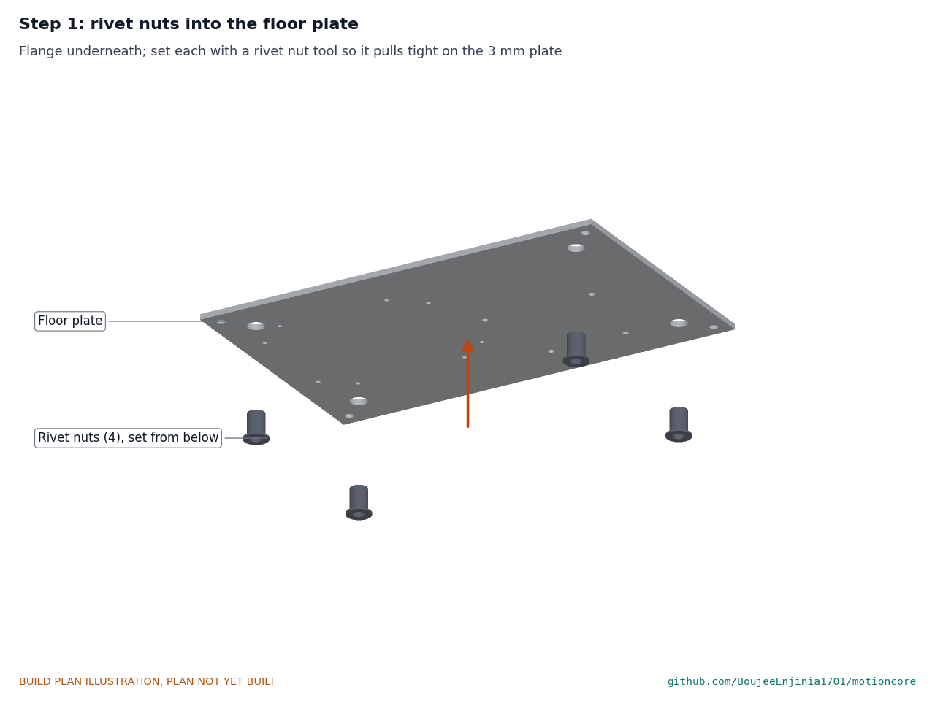
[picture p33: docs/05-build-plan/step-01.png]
Step 1


From below, flange underneath; set each with the rivet nut tool.

### Step 2: sockets and vent into the finned tube

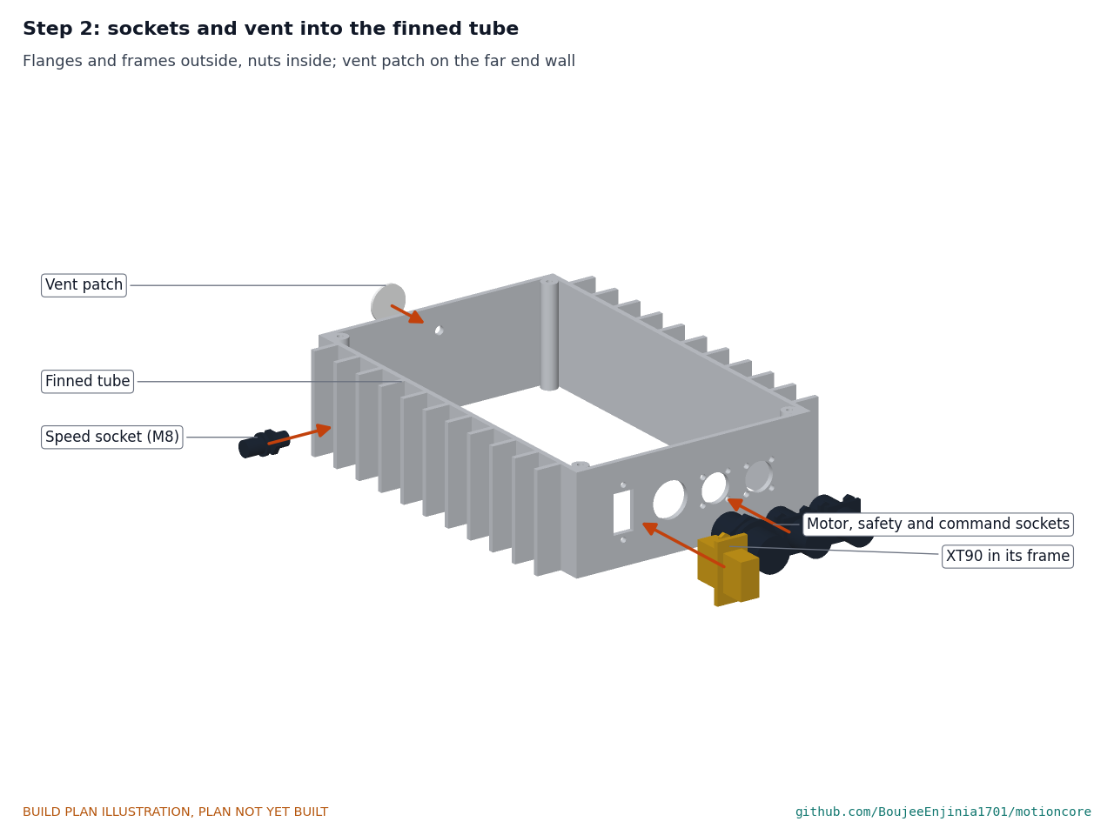
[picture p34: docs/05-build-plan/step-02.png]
Step 2


Each socket from outside on its sealing ring, screws or nut inside; the vent patch on the far end wall.

### Step 3: finned tube onto the floor plate

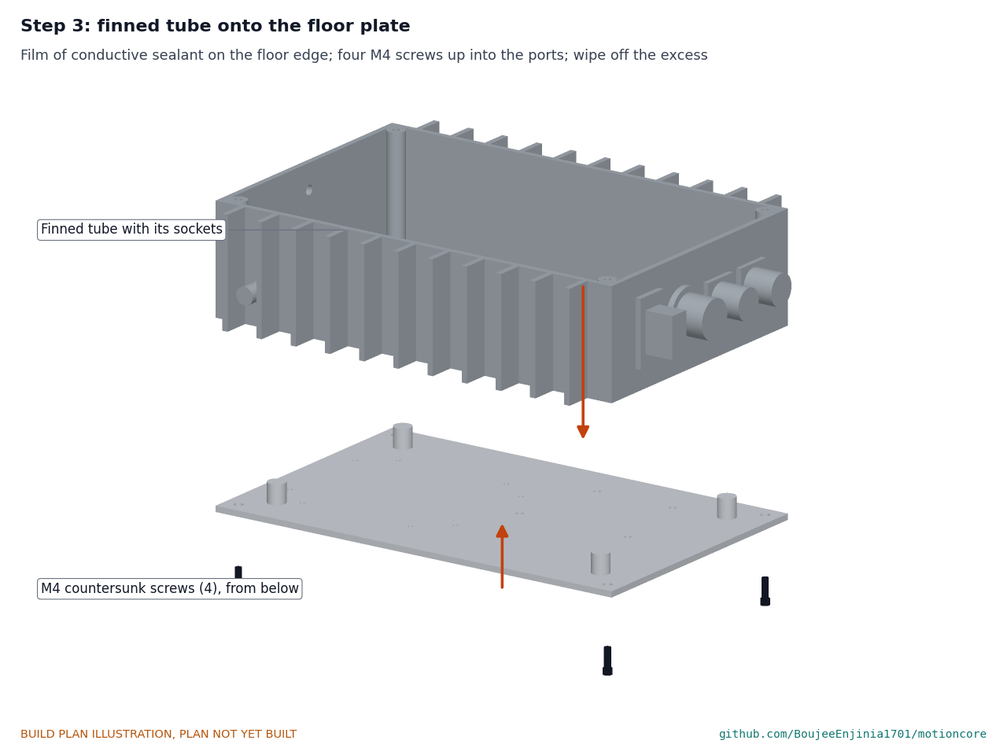
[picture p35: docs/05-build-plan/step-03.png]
Step 3


A thin film of conductive sealant where the walls and ports land; tube on, edges flush; four M4 countersunk screws from below, tightened evenly; wipe off the excess. Let the sealant cure for the time its maker states before step 7.

### Step 4: controller onto the floor

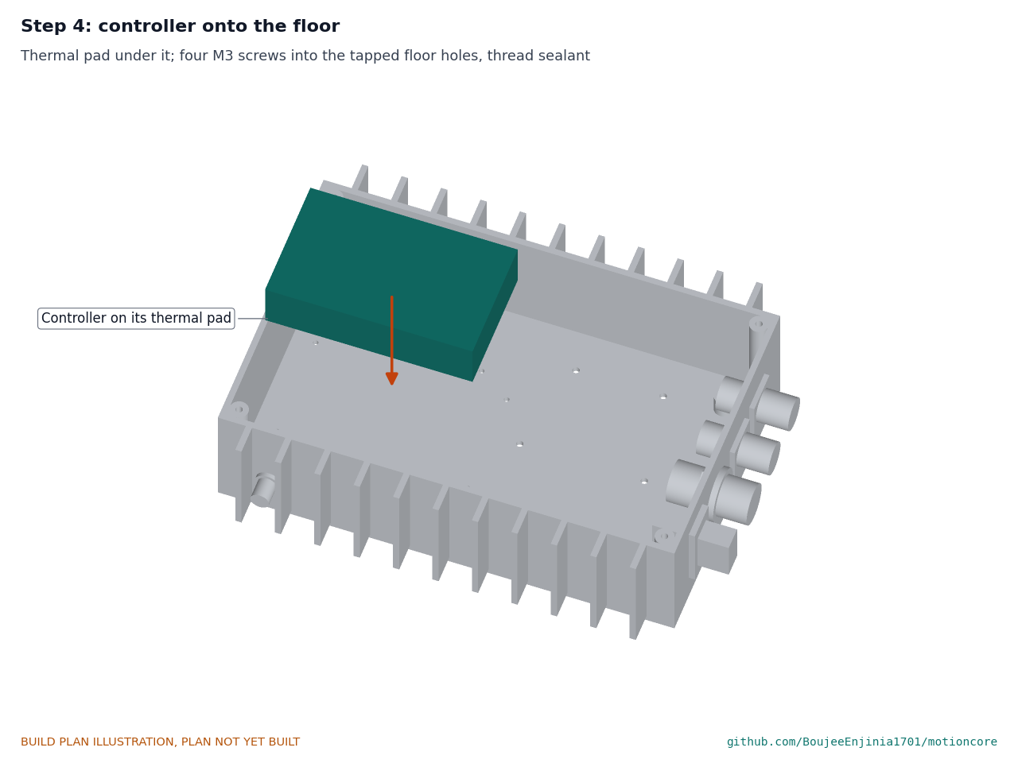
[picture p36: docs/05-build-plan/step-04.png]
Step 4


Thermal pad under it; four M3 screws with thread sealant.

### Step 5: contactor and precharge and fuse block

Step 5

Two M4 screws each with thread sealant. Then the power wiring of section 3.6.1, items 1 to 3. **Hold point:** the fuse stays out of its holder.

### Step 6: standoffs and supervisor board

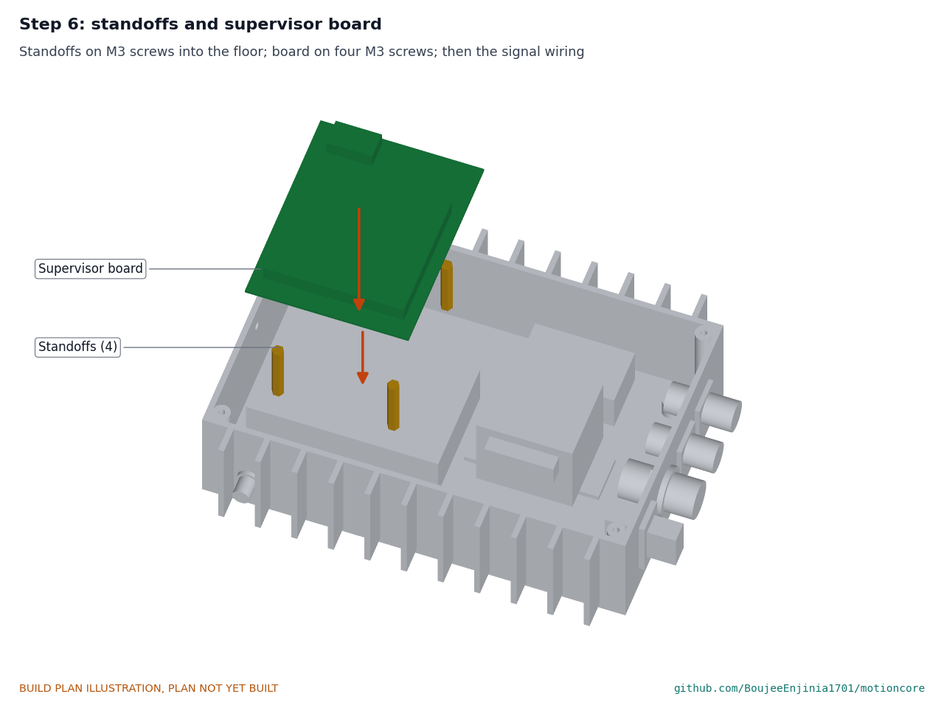
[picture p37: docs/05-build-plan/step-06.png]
Step 6


Standoffs on M3 screws into the floor; the board on four M3 screws. Then the rest of the wiring of section 3.6.1. **Hold point:** the wiring checks of section 3.6 pass.

### Step 7: gasket and lid

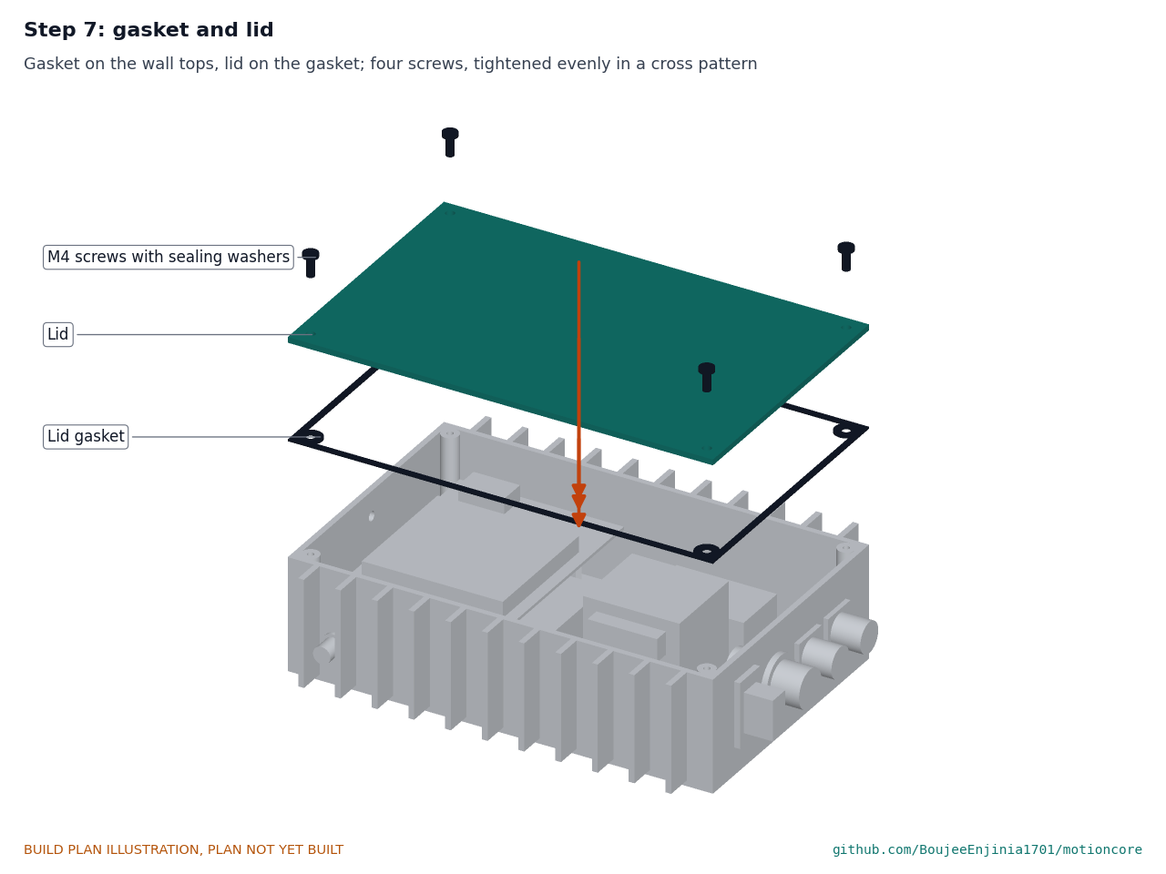
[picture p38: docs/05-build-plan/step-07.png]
Step 7


Gasket on the wall tops, lid on the gasket; four button-head screws with sealing washers, tightened evenly in a cross pattern. Leave the lid off until the first power checks of section 5 are done if you want to probe inside; fit it before the motor runs.

### Step 8: module onto the bench board

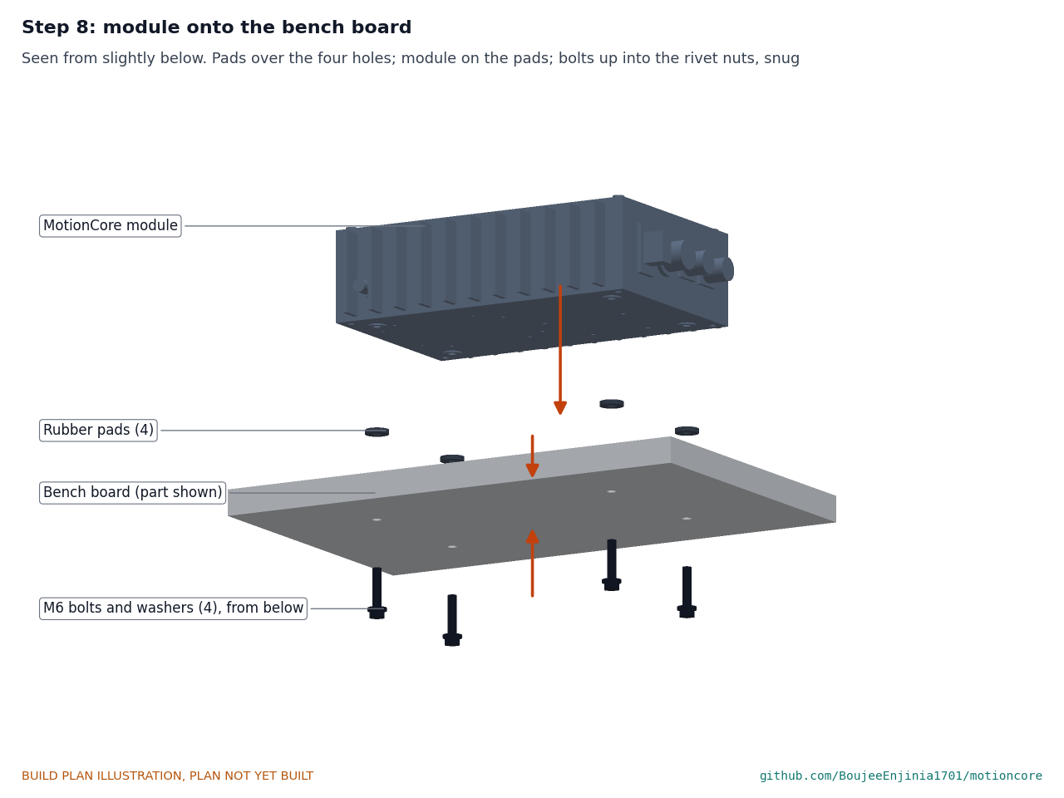
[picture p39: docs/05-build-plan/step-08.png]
Step 8


Pads over the four holes, module on the pads; four M6 x 30 bolts with washers up through the board into the rivet nuts, snug, not crushing the pads.

### Step 9: motor uprights onto the board

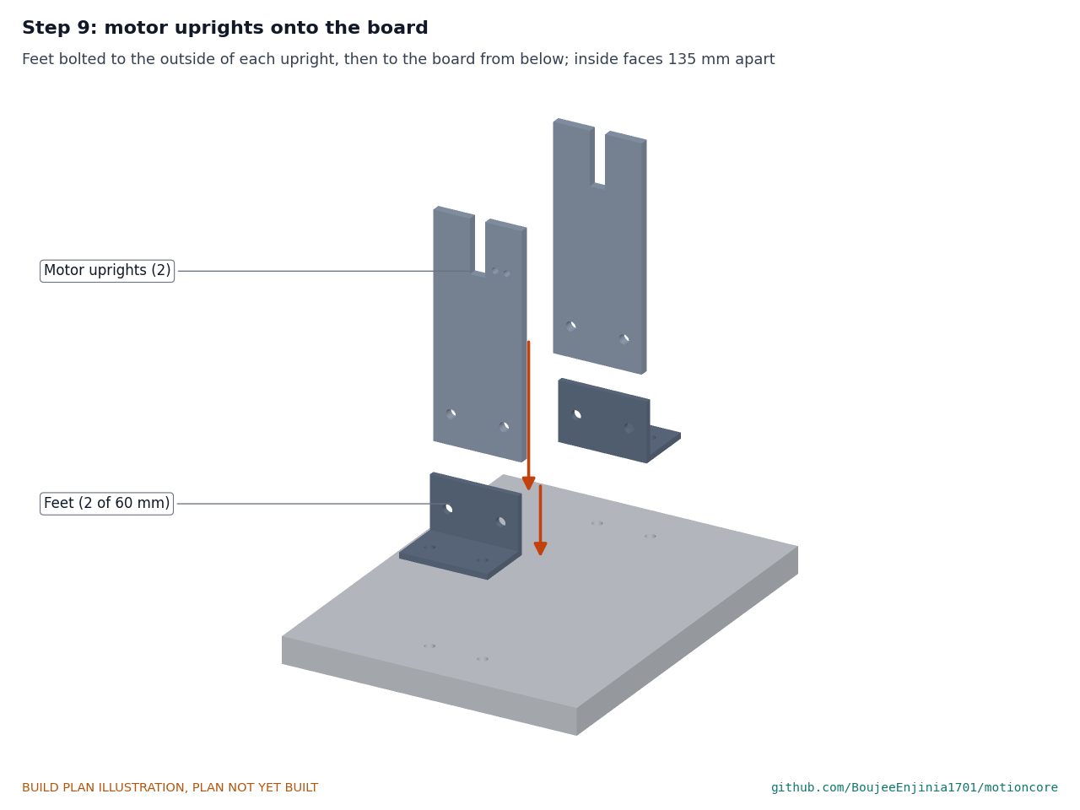
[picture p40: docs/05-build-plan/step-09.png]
Step 9


Each upright bolted to a 60 mm foot, then each foot bolted to the board from below; inside faces 135 apart, square to the board.

### Step 10: magnet ring onto the motor

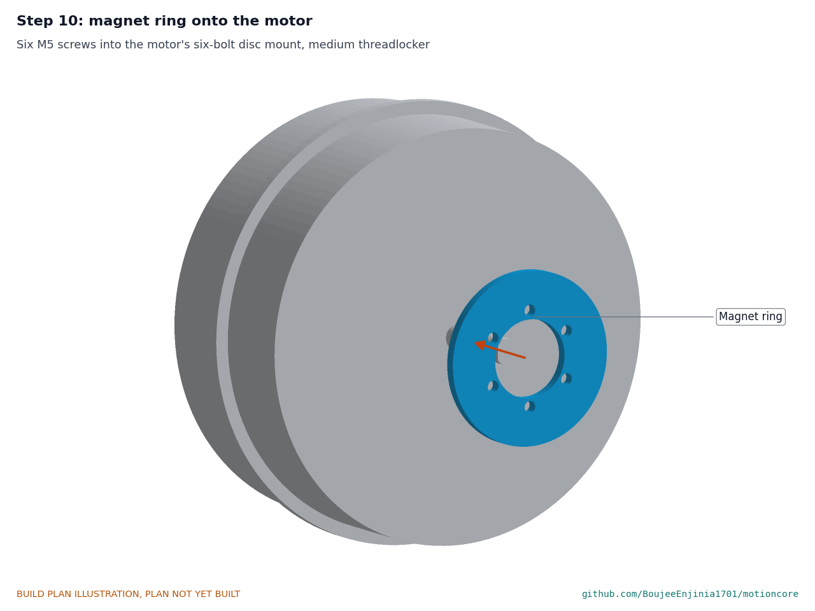
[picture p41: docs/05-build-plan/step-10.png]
Step 10


Six M5 screws into the motor's six-bolt disc mount, medium threadlocker.

### Step 11: Hall bracket and pickup onto the upright

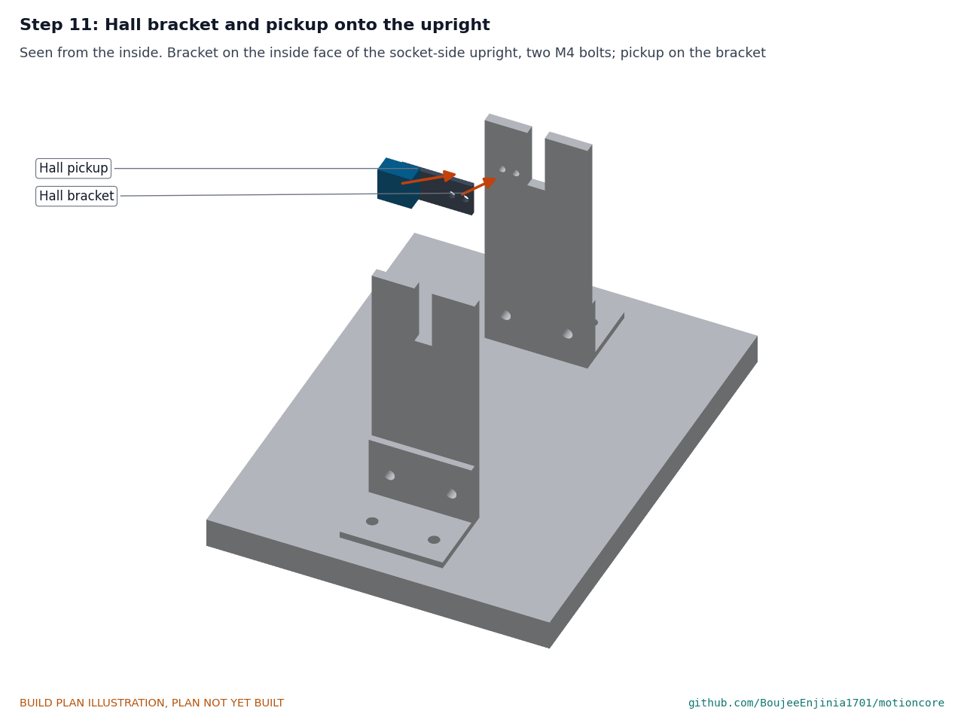
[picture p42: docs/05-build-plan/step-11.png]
Step 11


Bracket on the inside face of the front-edge upright, two M4 bolts with the nuts inside; pickup on the bracket. Fit it now: it is hard to reach with the motor in place.

### Step 12: motor into the uprights

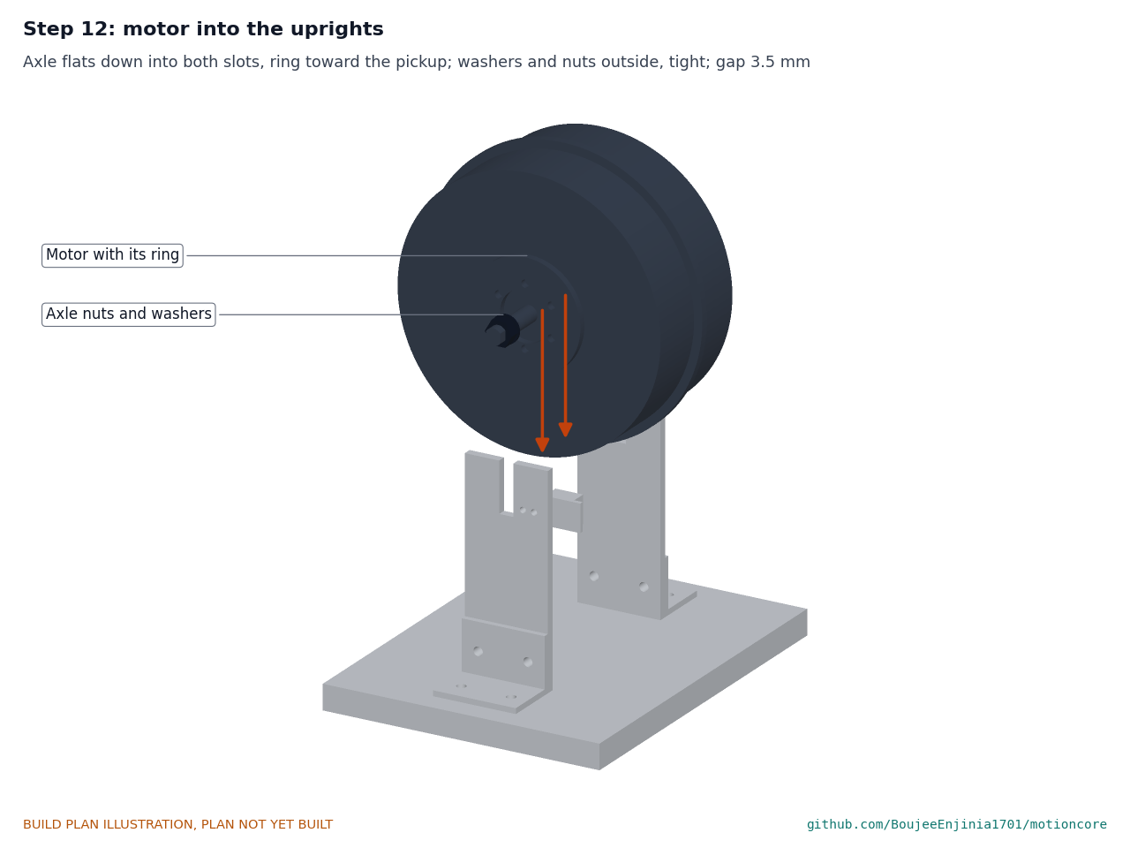
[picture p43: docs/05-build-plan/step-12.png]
Step 12


Lower the motor so the axle flats drop into both slots, ring toward the pickup; washers and axle nuts outside, to the motor maker's torque. Check the 3.5 gap.

### Step 13: bar posts and handlebar stub

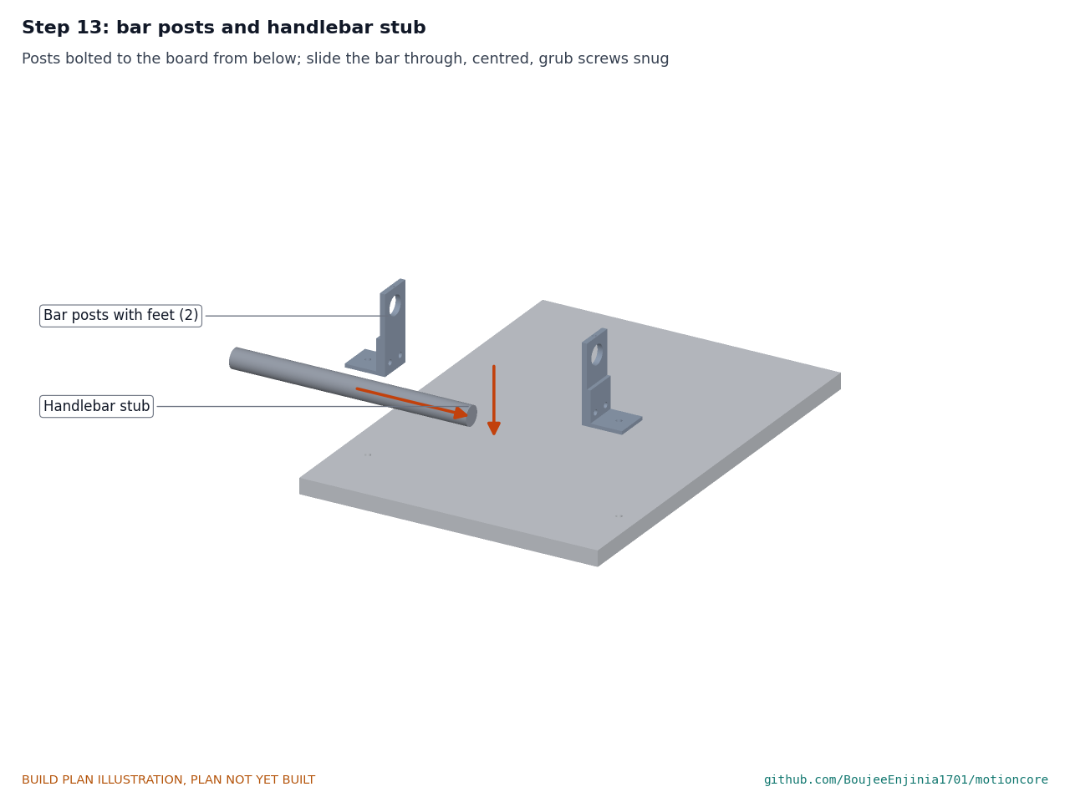
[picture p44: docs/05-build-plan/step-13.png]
Step 13


Posts on their 40 mm feet, bolted to the board from below; slide the bar through both, centred; grub screws snug.

### Step 14: brake levers and pod onto the bar

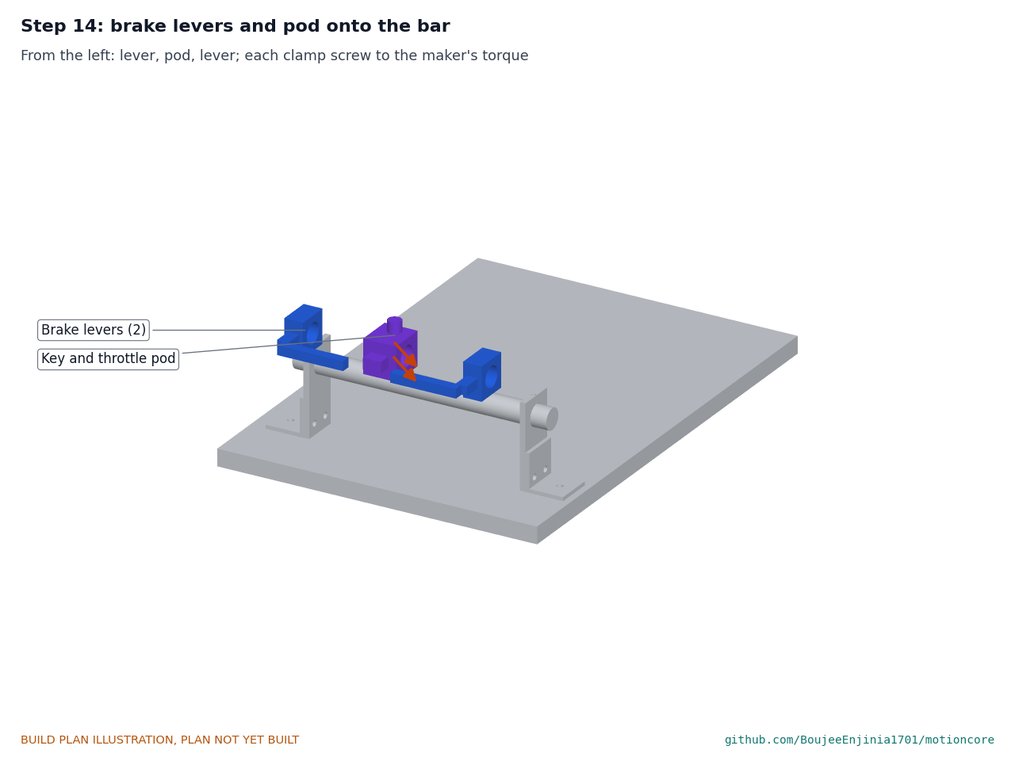
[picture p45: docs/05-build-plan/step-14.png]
Step 14


From the left: lever, pod, lever; each clamp screw to its maker's torque.

### Step 15: e-stop station onto the board

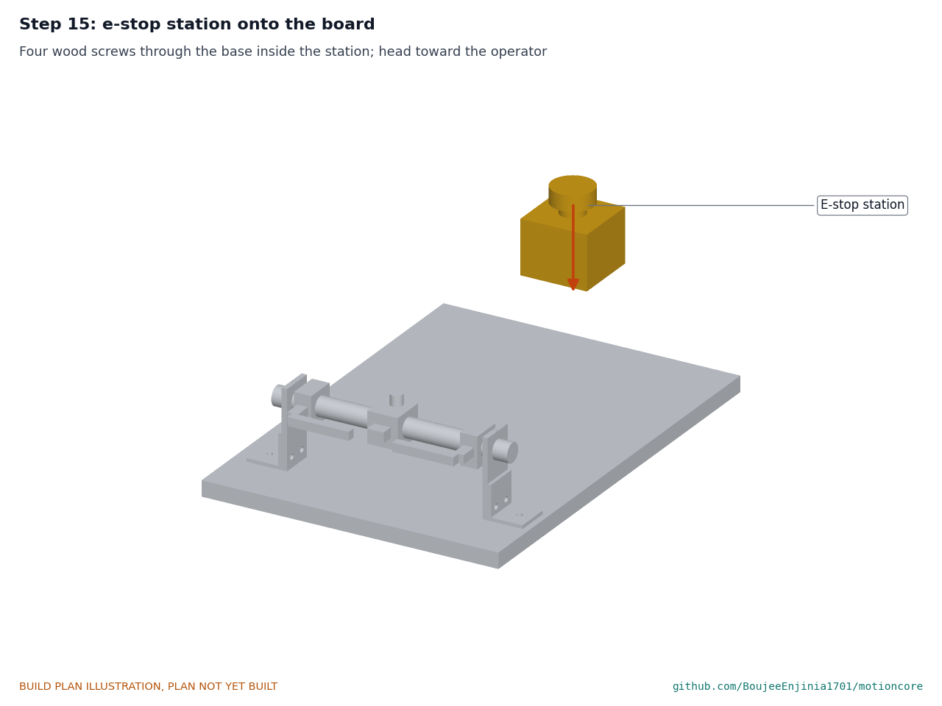
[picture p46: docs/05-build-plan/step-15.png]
Step 15


Four wood screws through the base inside the station, head toward the operator's side of the board.

### Step 16: harness

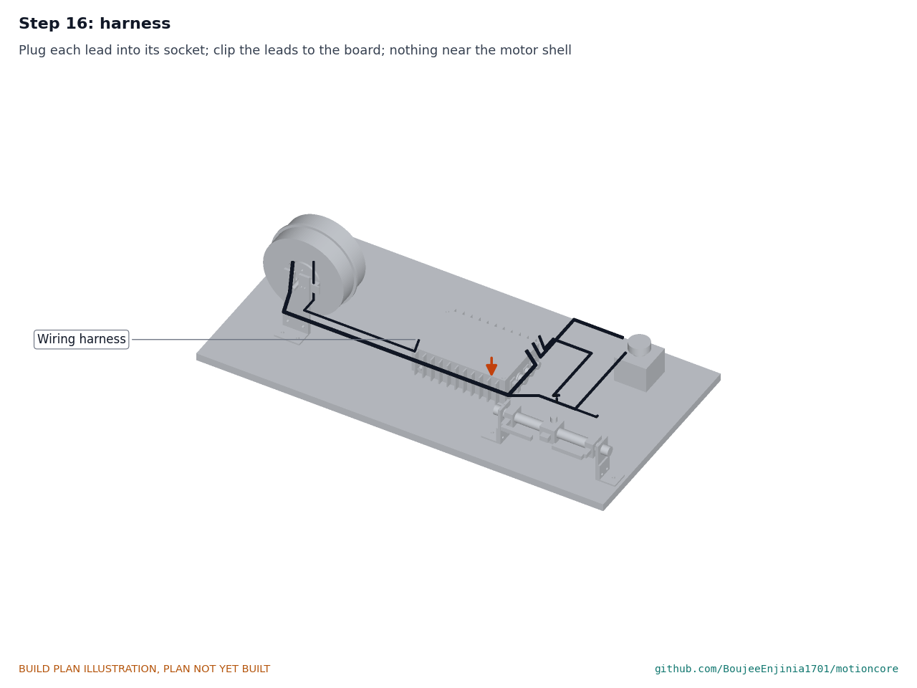
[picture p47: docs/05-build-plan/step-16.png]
Step 16


Plug each lead into its socket and clip it to the board, every lead at least 50 mm from the motor shell. **Hold point:** safety stop S1 of section 6.

## 5. First checks

These are the checks a TRL 4 test report would record; this plan only lists them. Requirement numbers are those of MTC-REQ-001.

*Table 4. First checks.*

| Check | Requirement | How | Pass when |
| --- | --- | --- | --- |
| Size and mass | R12 | Measure and weigh the module off the board | Within 250 x 170 x 70 mm; 2.0 kg or less (1.91 kg estimated) |
| Sealing of the build | R10 | Look at every socket ring, the lid gasket and the floor joint under a lamp | Every ring and the gasket evenly squeezed; sealant line unbroken (spray testing comes later) |
| Supply range and supervisor start | R1 | Bench supply, current limit 1 A, raised from 0 to 25 V, fuse in, motor unplugged | The supervisor starts above about 18 V; nothing gets warm |
| Precharge | R8 | Scope across the precharge resistor at power-up from 25 V | Current under 5 A; the contactor closes only after about 0.6 s and only with the bus at 90 % or more |
| No automatic restart | R4 | Power up with the key on, then with the throttle open | The contactor stays open until the key is cycled with the throttle at zero |
| E-stop | R3 | Scope on the contactor's main contacts; press the e-stop with the motor turning slowly | Power removed within 100 ms; the motor stays off until reset |
| Coil economizer | R3, R9 | Bench, contactor closed: coil supply current after the first second; then press the e-stop and time the contactor opening from the loop opening | Coil held at about 1 W (about 83 mA at 12 V); contactor open within 50 ms of the loop opening |
| Brake interlock | R5 | Pull each lever with the motor turning slowly | Drive torque removed within 200 ms of either lever |
| Independent speed limit | R6 | Set a low test limit; turn the wheel faster than it by throttle | The contactor opens after the overspeed has lasted 0.5 s |
| Fault reaction | R7 | Unplug the command plug, then the internal CAN, with the motor turning slowly | Torque removed within 200 ms of each |
| Case temperature | R9 | Thermocouples on a fin, the lid and the floor plate edge during a 30 minute run under load | Plotted against the calculation; the heavy case is not run on the bench |
| Fit to a host | R11 | Time taking the module off the board and refitting it with hand tools | Logged as a first estimate of the 2 hour target |

## 6. Safety stops

Stop at each point. Carry on only when everything listed is true.

- **S1. Before the first power-up.** Lid fitted or the inside covered; the main fuse out; every wire checked end to end; no battery in the room. The bench supply is a certified unit set to 25 V with a 1 A limit, and its output reads correct on a meter.
- **S2. Before the fuse goes in.** With the bench supply off, the power socket's pins read no short; the controller's bus reads open to the case; the coil loop opens when the e-stop is pressed.
- **S3. Before the motor is plugged in.** The precharge, no automatic restart and e-stop checks of section 5 pass on the bench supply with the motor unplugged (the contactor heard and seen to open).
- **S4. Before the motor first turns.** The motor's axle nuts are tight and the axle cannot turn in its slots; the wheel is clear of the board and of every lead; nobody stands in line with the wheel; a second person has a hand on the e-stop; the speed limit is set low; loose clothing, hair and jewellery are tied back or removed.
- **S5. Before a battery is connected (after the bench supply checks).** The pack has its own battery management system and fuse; its voltage is inside 20 to 60 V; the main fuse matches it (20 A for 36 and 48 V, 40 A for 24 V) and is rated 60 V DC or more with 1 kA breaking capacity; the pack is plugged in through the anti-spark socket with the key off; and the pack sits on a non-combustible surface with an extinguisher for electrical fires within reach.
- **S6. Every session.** Press the e-stop once before the first run and see the contactor open. Never bridge the safety loop with a jumper. After the pack is unplugged, wait one minute and check the controller's bus reads under 5 V before opening the lid.

## 7. Tools, skills and workspace

**Tools.** Bench drill or a drill in a stand; drills 2.5 to 10 mm; step drill to 22 mm; countersink; taps M3, M4 and M5 with tap wrench; M6 rivet nut tool; hacksaw with a 32 teeth per inch blade (or a bandsaw); jigsaw for the plywood; flat, half-round and needle files; deburring tool; scriber, square, steel rule and calipers; flat plate and abrasive paper; sealant gun; crimper for 4 mm² ring lugs and for M12 and M8 field plugs; wire strippers; soldering iron; multimeter; bench power supply 0 to 30 V with an adjustable current limit; two-channel oscilloscope (for the timing checks); thermocouple meter; torque screwdriver and torque wrench covering about 1 to 40 N·m; kitchen or hanging scale to 5 kg; stopwatch.

**Skills.** No certified trade is needed. Basic metalwork (marking out, sawing, drilling, tapping, setting rivet nuts), crimping and through-hole soldering, safe use of a bench power supply, and care with lithium batteries and with a turning wheel. All circuits are extra-low voltage, 60 V DC at most; no mains wiring is part of this build. The battery's short-circuit current is the main hazard: treat its leads as live at all times.

**Workspace.** A sturdy bench at least 1.2 x 0.6 m that the board can be clamped to; a metalwork corner kept apart from the electronics so chips stay off the boards; good light; a clear zone of 1 m round the wheel during runs; a non-combustible surface for any battery.

**Personal protective equipment.** Safety glasses for cutting, drilling, soldering and every powered run; cut-resistant gloves for handling bar and plate; hearing protection when sawing; no gloves near a turning drill or a turning wheel.

## 8. Where the numbers come from

- Model and constructability checks: `cad/src/model.py` (`python cad/src/model.py --check`); STEP and STL exports in `cad/step/` and `cad/stl/`.
- Pictures: `cad/src/build_plan_media.py`, using `.kit/build_views.py`; written to `docs/05-build-plan/` and `cad/drawings/MTC-DWG-101` to `MTC-DWG-110`.
- General arrangement: `cad/drawings/MTC-DWG-001.pdf`, Rev P4.
- Calculations: `docs/04-calcs/01-sizing.md` (MTC-CAL-001 v0.5) and `docs/04-calcs/sizing.py`: thermal and floor joint (section 4), mass (section 9), cost (section 10).
- Bill of materials: `bom/bom.csv` and `bom/bom-notes.md`.
- Decisions: `docs/decisions/0003-design-for-construction.md` (MTC-DDR-003), with MTC-DDR-001 and MTC-DDR-002; open items in `docs/06-design-decisions.md` (MTC-DEC-001).
- Requirements: `docs/03-requirements.md` (MTC-REQ-001 v0.7).

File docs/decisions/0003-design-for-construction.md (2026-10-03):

---
doc_id: MTC-DDR-003
title: MotionCore design for construction
project: MotionCore
doc_type: Design decision record
version: "0.3"
status: Draft
date: '2026-10-02'
author: Amish Chadha
license: CERN-OHL-S-2.0
revisions:
- version: "0.1"
  date: '2026-10-01'
  author: Amish Chadha
  change: Changes that make the concept physically buildable, with the reason for each; made under Amish's 2026-09-30 instruction to make the design physically buildable; open for his review
- version: "0.2"
  date: '2026-10-02'
  author: Amish Chadha
  change: "Accepted by Amish (2026-10-02), with A1 to A3 as recommended; status kept Draft"
- version: "0.3"
  date: '2026-10-02'
  author: Amish Chadha
  change: 'A3 economizer carried into the design; appearance model brought into line with the constructable design'
---

# 0003: Design for construction

- **Date:** 2026-10-01
- **Status:** accepted. Amish, 2026-10-02: "i approve your recommendations for all 555 open decisions." This covers every change in Tables 1 and 2 and the recommendations for A1 to A3 in Table 3, which are now decided as recommended and recorded in the design decisions register (MTC-DEC-001).

## Context

On 2026-09-30 Amish asked for every repo's build plan to show how each component is made and how it fits the next, with pictures, and wrote: "If you are realising that the design cannot be built as per concept - fix the design assumptions to match and be physically feasible as you draw the illustrations." The concept model of MTC-PRC-001 v0.4 showed what MotionCore does but had parts that could not be made, fixed or connected as drawn. Checking it with build123d found an overlap of 3,300 mm³ between the supervisor standoffs and the controller, a connector panel standing outside a closed wall with no holes through it, connectors closer together than their own flanges, and several parts with no fixing at all. The reference kit was laid loose on a bench with the motor standing on its shell, so it could not be run with the wheel off the ground as the safety section requires.

The changes below keep what MotionCore does: the same controller, supervisor, contactor, precharge and fuse, the same hardwired e-stop loop and twin speed check, the same host mounting interface (four M6 on 180 x 100 mm), the same four interface connectors and the same finned aluminum heat sink. Nothing here changes the pitch or the safety case. Every change is in `cad/src/model.py`, which now runs 111 constructability checks (`python cad/src/model.py --check`): parts that must touch do touch, and parts that must not touch are apart by at least the stated clearance. All 111 pass.

## Options considered

For the enclosure, three routes keep a finned aluminum heat sink: (a) a cut length of finned enclosure extrusion with a separate floor plate, (b) heat-sink slices bolted to a plain die-cast box, (c) a body machined from solid. Option (b) doubles the wall where the fins attach and adds about 0.19 kg, which breaks R12's 2.0 kg limit. Option (c) costs several times the USD 22 line and is not a garage process. Option (a) keeps one wall thickness and the vertical fins, and is chosen. For the other changes the simplest sound fix was taken; the alternatives are noted in Table 1.

## Decision

*Table 1. Changes made to the model, the BOM and the calculations.*

| # | Problem in the concept | Change made | Why this way |
| --- | --- | --- | --- |
| P1 | The body was an "extruded" box with an integral floor and vertical fins. An extrusion cannot have a closed floor and fins that run across its length. | The walls and fins are a 56 mm length cut from a finned enclosure extrusion (220 x 140 mm outside the walls, 3 mm walls, eleven 3 x 14 mm fins per long side on a 19 mm pitch, four screw ports in the inside corners), standing on a separate 3 mm 6061 floor plate. The joint is a film of thermally conductive silicone sealant on the wall and port end faces, pulled together by four M4 countersunk screws from below into the ports. | One wall thickness, fins still vertical for natural convection, and the controller still sits on aluminum that is bolted to the fins. Fins drop from 4 to 3 mm (typical for extrusions) and now run the full tube height, so the fin area rises from 0.0338 to 0.0382 m². |
| P2 | The lid had a 3 mm lip inside the walls, which clashes with the corner screw ports; the lid had no fixing. | Flat 3 mm lid on a 1 mm closed-cell EPDM gasket frame, four M4 button-head screws with bonded sealing washers into the same corner ports. | The ports take both the floor and lid screws; button heads keep the module under 70 mm tall. |
| P3 | Four M6 inserts were drawn in cast bosses, which a 3 mm plate floor cannot carry. | Four M6 closed-end rivet nuts set in the floor plate from below, flanges outside; the rubber isolation pads (16 x 3 mm) sit under the flanges. | The host interface is unchanged (four M6 on 180 x 100 mm) and the closed end keeps the floor sealed. |
| P4 | The supervisor's standoffs stood inside the controller's footprint: 3,300 mm³ of overlap. | Supervisor carrier board 85 x 88 mm (was 85 x 60), on four 35 mm M3 standoffs placed outside the controller, 4.2 mm clear of it; 10 mm of air between the controller and the board. | The board stays over the controller where the concept put it; a wider board is free because it is a made part. |
| P5 | The connector panel was a plate on the outside of a closed end wall, with no holes or socket bodies inside; the four connectors were 24 mm apart, less than their flanges and nuts. | The sockets go straight through the 3 mm end wall, so the separate panel plate is dropped. XT90 stood on end in a two-screw panel frame; motor socket nut-mounted; both M12 sockets on 20 mm four-screw square flanges. Centres 28, 56, 83 and 109 mm from the socket-side face, 28.5 mm above the tube's bottom edge. | Every flange and nut has at least 4 mm to its neighbour, the rear bodies clear everything inside by 3 mm or more, and the XT90 can be swapped for a sealed connector by recutting one hole. |
| P6 | The precharge and fuse block sat 8 mm from the panel, in the path of the socket bodies. | Moved beside the contactor on the plain side (+Y), 52 x 30 mm footprint. | Leaves 20 mm behind the end wall for socket bodies and wiring. |
| P7 | The controller, contactor and fuse block had no fixings. | M3 (controller, standoffs) and M4 (contactor foot, fuse block) screws into holes tapped through the floor plate, with thread sealant; contactor on a 3 mm mounting foot. | The plate is too thin for blind holes; sealant keeps the floor sealed. |
| P8 | The independent speed sensor had no connector: the 8-pin safety loop and 5-pin command sockets have no free pins for its 5 V, ground and signal. | An M8 4-pin A-coded socket in the socket-side wall, between the first two fins from the far end, 18 mm above the tube's bottom edge. It stays inside the fin depth, so the envelope does not grow. | R11 already lists "sensors" in the connector set; the socket is the simplest way to bring the sensor in. See A1. |
| P9 | The vent plug in the BOM was not modelled; an M12 vent on an end wall would push the length past R12's 250 mm. | Adhesive membrane vent, 20 mm, over a 5 mm hole in the far end wall, 43 mm above the bottom edge. | 1.5 mm proud; the envelope stays at 240 mm long. |
| P10 | The magnet ring floated 1.5 mm off the motor and the Hall pickup floated in the air. | Ring bolted to the motor's six-bolt disc mount (44 mm circle, M5); pickup on a 20 x 3 mm bracket on the inside face of the socket-side motor upright, 3.5 mm from the ring over the 34 mm magnet circle. | Uses the mounting the reference hub already has. |
| P11 | The reference kit lay loose on a bench with the motor standing on its shell, so the drive could not run with the wheel off the ground. | A bench rig (new BOM line 15, not part of the MotionCore kit): 18 mm plywood board 960 x 480 mm; two 60 x 6 mm uprights with 10.2 mm slots that take the axle flats (axle 120 mm up, shell 19 mm clear of the board) on 40 x 40 x 4 mm angle feet; two bar posts carrying a 22.2 mm handlebar stub; the e-stop station screwed to the board; the module bolted through its own interface. | Lets the first build be run as the safety section asks, and exercises the host mounting interface. |
| P12 | The brake switches were blocks with no mounting. | E-bike brake levers with built-in normally closed cut-off switches, clamped on the handlebar stub with the key and throttle pod between them (BOM line 10, USD 7 each). | Real parts that clamp where a host's controls go. |
| P13 | The harness routed the power socket's lead to the motor and the motor socket's lead to the brake switches. | One lead per socket: motor socket to the motor, safety loop to the e-stop station with a branch to both brake levers and the key, command to the pod, M8 to the speed pickup. | Matches the interface. |
| P14 | No pin assignment existed for the safety loop, command and speed sockets. | A pin-out that fits each socket (build plan Table 3): safety loop 1 loop supply, 2 loop return, 3 e-stop B, 4 brake A, 5 brake B, 6 brake coil output, 7 ground, 8 spare; command 1 +5 V, 2 throttle, 3 ground, 4 CAN high, 5 CAN low; speed 1 +5 V, 3 ground, 4 signal. | The harness can be made; see A1. |

*Table 2. Knock-on changes.*

| Item | Change | Reason |
| --- | --- | --- |
| Size | Module 240 x 168 x 69 mm (was 243 x 168 x 66 mm): no panel plate, a 1 mm lid gasket, lid screw heads and a 1 mm rivet nut flange; tube height 56 mm so the total stays under 70 mm. Inside R12's 250 x 170 x 70 mm. | P1 to P5 |
| Mass | Module about 1.91 kg (was 1.94 kg): enclosure metal 1.00 kg, parts 0.91 kg; 0.09 kg under R12's 2.0 kg (MTC-CAL-001 v0.3 section 9). | Thinner fins and no panel plate offset the rivet nuts, gasket, screws and the wider supervisor board. |
| Thermal | Walls and fins: 50.2 °C reference, 58.4 °C heavy (58.5 °C before). The floor joint adds about 0.8 K (reference) and 1.6 K (heavy) between the floor plate and the walls, so the floor plate reaches about 51.0 °C and 60.0 °C, and the MOSFETs about 2 K more. R9 stays at risk. | P1 |
| Cost | Value-engineering target USD 300. Estimated cost of the constructable MotionCore kit (items 2 to 14) USD 293, USD 7 under the target (was USD 265): lines 6, 8, 10, 12, 13 and 14 repriced. Reference motor USD 70 to each host; bench rig USD 35, prototype only. | P1, P3, P5, P8, P9, P12, P13 |
| Drawings | MTC-DWG-001 Rev P3; making sketches MTC-DWG-101 to 110; concept sheet MTC-DWG-010 Rev P4. | Follows the model. |
| Documents | MTC-CAL-001 v0.3, MTC-REQ-001 v0.5, MTC-PRC-001 v0.5, `bom/bom.csv` and `bom/bom-notes.md`. No requirement changed status. | Follows the model. |

*Table 3. Items proposed to Amish; accepted as recommended on 2026-10-02.*

| # | Question | Options | Recommendation |
| --- | --- | --- | --- |
| A1 | Interface v0.1 was decided as four connectors (MTC-DDR-001 item 6). The speed sensor needs a fifth, and the pin-out was never set. | (a) M8 4-pin speed socket and the Table 1 P14 pin-out, as modelled, as interface v0.2; (b) a 12-pin M12 safety loop socket that also carries the speed sensor, keeping four connectors. | (a): cheaper sockets, the speed sensor lead stays short, and the 8-pin loop keeps a spare pin. Accepted 2026-10-02: interface v0.2 is issued with the M8 speed socket and this pin-out, and CargoMule is told of the fifth socket. |
| A2 | The bench rig (P11) adds a board, motor stand and handlebar stub to the prototype. | (a) build it with the first prototype, outside the kit total; (b) mount the first prototype straight on CargoMule. | (a): it lets the safety functions be checked with the wheel off the ground before any host is involved. Accepted 2026-10-02. |
| A3 | The floor joint adds 1.6 K in the heavy case, so the floor plate reaches the 60 °C limit of R9. | (a) accept, with R9 still at risk; (b) fit the contactor coil economizer already listed as open item 19 of MTC-DDR-002 (walls about 55.6 °C, floor about 57 °C); (c) bond the floor with thermally conductive epoxy (not removable). | (b), decided together with open item 19. Accepted 2026-10-02: the economizer is fitted, wired so the safety loop breaks the coil supply upstream of it, so a stop still drops the contactor within 50 ms. |

## Consequences

- `design_state: constructable` in `project.yaml`. The build plan MTC-BLD-001 shows every component and step in pictures drawn from the model (`cad/src/build_plan_media.py`), and the open items are in the design decisions register MTC-DEC-001.
- With A3 accepted on 2026-10-02, the coil economizer is in the design (carried out the same day): a module on the supervisor carrier board, which grows from 85 x 88 mm to 85 x 108 mm, BOM line 3 at USD 34 (was USD 30), the loop break upstream of it in the wiring picture and build plan, and the thermal and e-stop timing results in MTC-CAL-001 v0.5 (heavy case 55.6 °C on the walls and 56.9 °C on the floor plate; worst-case stop 74 ms). A1 is issued as interface v0.2 in the precis.
- Requirement status at the time of this record (MTC-CAL-001 v0.3): none not met; R2, R9 and R10 at risk; R11 not verifiable at TRL 3; the rest met on paper or by design review. With the economizer (v0.5) R2 and R9 are met on paper.
- The photoreal renders (`media/render-*.png`), `media/card.png`, `media/social-preview.png` and the appearance model `cad/src/product_model.py` are made next on Amish's Mac, where Blender is. The appearance model now follows the constructable design (floor plate joint, rivet nuts, sockets through the wall with flanges, M8 speed socket, wall vent, moved fuse block, lengthened supervisor board with the economizer); the lid window, lights, two-flange hub, layout and harness remain render-only.
- The extrusion profile, the controller's mounting holes and the reference motor's axle width and disc mount are confirmed when parts are bought; the floor plate, tube and upright holes move to suit.

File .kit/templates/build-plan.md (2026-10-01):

---
doc_id: PRJ-BLD-001
title: Project prototype build plan
project: Project name
doc_type: Build plan
version: "0.1"
status: Draft
date: YYYY-MM-DD
author: Amish Chadha
license: CERN-OHL-S-2.0
revisions:
  - version: "0.1"
    date: YYYY-MM-DD
    author: Amish Chadha
    change: First build plan; design made constructable
---

# Project prototype build plan

**Plan, not yet built.** How to build the first proof-of-concept prototype, component by component. Building and testing to it is TRL 4 work. Decisions still to be made are kept in the design decisions register (`docs/06-design-decisions.md`), not here.

## 1. What you are building

Every component, pulled apart and numbered in build order

One short paragraph: what the prototype is, how many components, which are made and which are bought, and the main ways they are made.

## 2. What changed to make it buildable

| Component | The concept had | The buildable design has | Why |
| --- | --- | --- | --- |

## 3. Making the components

### 3.1 Component name

Making sketch

**What it is and what it is made from.**

**How to make it.**

1. Mark out ...
2. Cut ...

**How it fits the parts next to it.**

Close-up of the joint

**Check before moving on.**

## 4. Putting it together

### Step 1: ...

Step 1

## 5. First checks

| Check | Requirement | How | Pass when |
| --- | --- | --- | --- |

## 6. Safety stops

## 7. Tools, skills and workspace

## 8. Where the numbers come from

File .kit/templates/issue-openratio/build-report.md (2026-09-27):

---
name: Build report
about: Tell us what happened when you built, printed or tested part of this design
title: "Build report: "
labels: build-report
---

This is a research and educational prototype, not a medical device. It is a TRL 3 concept and is not released for fabrication. If you build any part of it, you do so at your own risk. Reports help everyone.

**What you built** (part, sub-assembly or test)

**Materials, tools and settings**

**What worked**

**What did not work, with photos or measurements if you have them**

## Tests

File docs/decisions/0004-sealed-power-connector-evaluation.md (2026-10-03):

---
doc_id: MTC-DDR-004
title: MotionCore sealed power connector evaluation
project: MotionCore
doc_type: Design decision record
version: "0.1"
status: Draft
date: '2026-10-02'
author: Amish Chadha
license: CERN-OHL-S-2.0
revisions:
- version: "0.1"
  date: '2026-10-02'
  author: Amish Chadha
  change: Paper evaluation of sealed power connectors against the rule decided on 2026-10-02 (MTC-DEC-001); no part chosen
---

# 0004: Sealed power connector evaluation

- **Date:** 2026-10-02
- **Status:** proposed (evaluation done; no part chosen)

## Context

The power socket in interface v0.2 is an XT90 anti-spark plug, which is not sealed (R10 asks for IP65 on the enclosure and mated connectors). On 2026-10-02 Amish approved a paper evaluation now, against one rule, with the XT90 kept for the bench prototype only (MTC-DEC-001; MTC-DDR-002 item 18). This record is that evaluation. It is a TRL 3 paper task: nothing was bought, built or tested, and the figures below are the classes of rating to look for, to be confirmed against a named part's datasheet.

The rule: the mated connector is keyed so it cannot be reversed, is IP67 when mated, carries at least 40 A continuous at 60 V DC (the larger fuse rating of MTC-CAL-001), and leaves no exposed live contact on the pack side.

## Options considered

| Option | Keyed | IP67 mated | 40 A at 60 V DC | No live contact exposed on the pack side | Verdict |
| --- | --- | --- | --- | --- | --- |
| XT90 anti-spark plug in a panel frame (now) | By its shape | No | Yes (90 A class) | Anti-spark pin protects the first contact only | Bench prototype only |
| Industrial IP67 single-pole power connector, one for positive and one for negative (for example Amphenol's SurLok Plus class) | Yes, by colour and key coding between the two poles | Yes, as listed for the class | Yes, the class lists 50 A or more per pole and 600 V or more | Yes, touch-safe sockets on the receptacle side | First candidate class |
| XT90 or similar inside a sealed plastic boot or bulkhead cover | By shape | Only as good as the boot seal, with a cable gland | Yes | No: contacts stay bare inside the boot | Rejected: no touch protection, seal depends on assembly |
| Round multi-pin power connector (M23 class, several pins in parallel) | Yes | Yes | Needs three or four pins in parallel per line | Yes | Fallback: larger, dearer, and the pins must share current evenly |
| M12 power connector (L-coded, 16 A) | Yes | Yes | No: 16 A | Yes | Rejected: current too low |

## Decision

Proposed for Amish's confirmation: carry the industrial IP67 single-pole connector class forward as the sealed power connector, two receptacles in the end wall (positive and negative, with different key coding so they cannot be swapped), and keep the XT90 for the bench prototype only. The M23 class is the fallback if no single-pole part meets the rule at a sensible price.

## Consequences

- No part is chosen at TRL 3: the rule has to be checked against a named part's datasheet (ratings, panel cut-out, torque, cable cross-section for the pack leads), which belongs to the parts purchase at TRL 4. The end wall hole, socket frame and BOM line 8 therefore stay as they are and are marked as the bench prototype's XT90.
- When a part is chosen, the end wall needs two round or square holes in place of the 12 x 22 mm XT90 slot, and BOM line 8 changes (the XT90 is replaced by two receptacles and two cable plugs, priced from the chosen part).
- R10 stays at risk until a part is chosen and its datasheet confirms the rule; vibration is still not analysed.
- Interface v0.2 lists the power connector as "sealed single-pole pair, part to be chosen; XT90 on the bench prototype".

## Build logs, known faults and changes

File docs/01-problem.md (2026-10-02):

---
doc_id: MTC-PRB-001
title: MotionCore problem statement
project: MotionCore
doc_type: Problem statement
version: "0.5"
status: Draft
date: '2026-10-02'
author: Amish Chadha
license: CERN-OHL-S-2.0
revisions:
- version: "0.1"
  date: '2026-09-25'
  author: Amish Chadha
  change: Initial scaffold
- version: "0.2"
  date: '2026-09-25'
  author: Amish Chadha
  change: Populate to TRL 2 (problem, users, host projects, context, constraints, prior work, open questions)
- version: "0.3"
  date: '2026-09-25'
  author: Amish Chadha
  change: TRL 3. Budget scope (motor costed to hosts), SwapCell and CellGuard links, first host and input range adopted for TRL 3 pending Amish's review (MTC-DDR-001); CargoMule pack corrected to 12S LiFePO4
- version: "0.4"
  date: '2026-09-25'
  author: Amish Chadha
  change: Recommendations accepted by Amish (DDR-002). Input range 20 to 60 V (CellGuard 16S covered); MTC-DDR-001 items recorded as decided
- version: "0.5"
  date: '2026-10-02'
  author: Amish Chadha
  change: "Brushed and dual-motor host questions decided (MTC-DEC-001, 2026-10-02)"
---

# MotionCore problem statement

Each vehicle or machine concept in the lab re-specifies the same drive train and safety logic, and small teams rarely have time to get the emergency stop, speed limit and brake interlock right. MotionCore is a shared controller and safety module, with a named reference hub motor and one documented interface, so that each host design inherits a reviewed safety chain instead of inventing its own.

## The problem

Five existing lab designs drive a motor from a lithium pack: CargoMule (a 36 V, 250 W hub motor in a bicycle trailer), PalletPilot (two 24 V hub motors on a pallet jack), StepClimber (a 24 V worm gearmotor on a stair-climbing hand truck), SunSpoke (a 48 V, 250 W hub motor on a roadster bicycle) and DustRunner (12.8 V gearmotors on a panel-cleaning robot). Each one specifies its own controller, fuse, emergency stop, brake cut-off and speed limit, in its own words, with its own gaps. Three problems follow:

1. **Repeated effort.** The same parts (a brushless controller, a contactor, a fuse, a mushroom-head stop button, brake switches) are selected, wired and documented five times, and a fix found in one design does not reach the others.
2. **Uneven safety logic.** The safety function is the part most often left vague. Typical gaps in small builds are an emergency stop that only asks the firmware to stop, a speed limit held in the same controller that could fail, no interlock between the brake and the drive, and a restart that happens by itself when power returns. Machinery standards such as [ISO 13850](https://www.iso.org/standard/59970.html) (emergency stop) and [ISO 13849-1](https://www.iso.org/standard/73481.html) (safety-related control parts) describe how to avoid these, but they are written for industrial teams and are costly to read.
3. **Rising exposure.** Light electric vehicles and small machines are spreading fast. The IEA reports almost 10 million electric two-wheelers sold worldwide in 2025, about 14 % of all two-wheeler sales ([IEA Global EV Outlook 2026](https://www.iea.org/reports/global-ev-outlook-2026/trends-in-other-ev-modes)). In the United States, the Consumer Product Safety Commission estimates about 698,500 emergency department visits linked to micromobility products from 2017 through 2024 and records 533 deaths, 310 of them involving e-bikes ([CPSC, 2017 to 2024 report](https://www.cpsc.gov/s3fs-public/Micromobility_Products-Related_Deaths_Injuries_and_Hazard_Patterns_2017-2024.pdf)). These figures cover all causes, most of them crashes, so they show the scale of exposure rather than a failure rate of drive electronics.

## Users and context

| User | Need | Context |
| --- | --- | --- |
| Lab project lead (host designer) | Drop in a drive and safety chain with known limits and a documented interface; spend design time on what is new about the host | Designing a vehicle or machine at TRL 2 to 4 |
| Builder of a host prototype | Wire, configure and test the drive in a garage with hand tools and a multimeter, and know when it is safe to power up | Home or makerspace workshop, first power-up on a bench |
| Operator of a host machine | Stop the machine at once from a clearly marked button; never have it start by itself | Walk-behind machines (pallet jack, stair climber), cargo trailers, bicycles |
| People near the machine | Not be struck by a machine that runs away, over-speeds or restarts | Warehouses, sidewalks, stairwells, farms |
| Maintainer or repairer | Diagnose a fault from a fault log and swap a part without special tools or closed software | Local repair shop or the lab |

### Host projects (first-order envelope)

Table 1 lists the drive needs stated in the host READMEs. MotionCore is sized to cover the first four; DustRunner's 12.8 V system falls outside the 20 to 60 V input range.

*Table 1. Drive needs of existing lab host designs.*

| Host | Pack | Motor | Stop and brake need |
| --- | --- | --- | --- |
| SunSpoke | 48 V SwapCell (about 46.8 V nominal, 54.6 V full) | 250 W geared front hub | Brake cut-off on both levers; pedelec speed cutoff |
| CargoMule | 12S LiFePO4 (38.4 V nominal), 384 Wh | 250 W geared hub, 20 in wheel | Drive cut when the drawbar goes into compression; overrun brakes |
| PalletPilot | 25.6 V LiFePO4, 20 Ah | Two 24 V hub motors with spring-applied brakes | Two hardwired e-stops, safety relay, walking-pace limit |
| StepClimber | 24 V LiFePO4, 10 Ah | 24 V worm gearmotor with spring-applied brake | Stop on tilt; brake holds on stairs |
| DustRunner | 12.8 V LiFePO4 | Two small drive gearmotors | Out of the 20 to 60 V range |

### Operating environment

- **Supply:** LiFePO4 or lithium-ion packs from 8S LiFePO4 (about 25.6 V nominal, 29.2 V full) to 13S lithium-ion (54.6 V full) and 16S LiFePO4 (58.4 V full), including the portfolio's SwapCell pack and CellGuard-managed packs.
- **Power:** 250 W continuous reference, up to 500 W continuous on 24 V hosts; short peaks to about 750 W.
- **Climate:** 0 to 40 °C ambient in the working range, rain and dust on outdoor hosts, vibration from rough roads and stairs.
- **Speeds:** walking pace (about 1.5 m/s, 5.4 km/h) for walk-behind machines; up to 25 km/h for pedal-assist hosts.

## Constraints

- Garage-buildable prototype, $300 or less for the MotionCore kit (module and devices); the reference motor is costed to each host (MTC-DDR-001 item 1).
- Off-the-shelf, openly documented parts: a VESC-class controller ([VESC project](https://vesc-project.com/)), a DC contactor, standard fuses and industrial pushbuttons.
- The emergency stop must work without any firmware: a hardwired loop that opens the main contactor.
- One connector set shared by all hosts; keyed so that the safety loop and the command lines cannot be swapped.
- Compatible with SwapCell interface v0.3 (the supervisor acts as the vehicle host) and the CellGuard BMS where a host uses them (decided by Amish, 2026-09-25, MTC-DDR-001 items 7 and 8).
- Research prototype only. MotionCore does not make a host compliant with any machinery, vehicle or pedelec regulation; each host remains responsible for its own risk assessment.

## Out of scope

- Battery packs and their BMS (SwapCell and CellGuard cover these).
- Host-specific mechanics: wheels, frames, brakes, gearboxes and guards.
- Traction above about 1 kW or systems above 60 V DC.
- Certification to ISO 13849, IEC 61508 or vehicle type approval.
- Autonomy, navigation and obstacle sensing (hosts such as PalletPilot own those layers and feed a stop request into the MotionCore safety loop).

## Prior work

- **VESC.** An open brushless motor controller started by Benjamin Vedder, with open hardware designs and firmware for DC, BLDC and FOC control ([VESC project](https://vesc-project.com/); [firmware, GPL-3.0](https://github.com/vedderb/bldc)). It already has current, temperature and speed (ERPM) limits, CAN bus and a PC tool, and many low-cost variants are sold. It has no separate safety channel.
- **ODrive and SimpleFOC.** Open motor control for robotics ([ODrive](https://odriverobotics.com/); [SimpleFOC](https://simplefoc.com/)). Good for position control; like VESC, they leave the safety chain to the integrator.
- **Machinery safety practice.** [ISO 13850:2015](https://www.iso.org/standard/59970.html) sets the principles for emergency stop design; [IEC 60204-1](https://www.se.com/us/en/faqs/FA122781/) defines stop categories 0, 1 and 2; [ISO 13849-1:2023](https://www.iso.org/standard/73481.html) sets the architecture and performance levels for safety-related control parts. MotionCore borrows their structure (two channels, fail-safe contactor, no automatic restart) without claiming conformity.
- **Pedelec rules.** In the European Union, pedal cycles with assistance up to 250 W that cuts off at 25 km/h are excluded from type approval under [Regulation (EU) No 168/2013](https://eur-lex.europa.eu/legal-content/EN/TXT/PDF/?uri=CELEX%3A32013R0168); EN 15194 sets the product standard. This sets the default speed cutoff for pedal-assist hosts.
- **Commercial safety relays and drives.** Industrial drives with Safe Torque Off inputs and dual-channel safety relays solve the problem well, at a cost and size that suit factories, not garage prototypes.

## Open questions

On 2026-09-25 Amish decided to go with the recommendations on first host, SwapCell heartbeat, stop category and input range (MTC-DDR-001, MTC-DDR-002): CargoMule is the first adopter, subject to its project's agreement; the supervisor sends the SwapCell heartbeat; category 0 is the default with category 1 as a per-host option; and the range is 20 to 60 V, which covers CellGuard's 16S LiFePO4 packs, so DustRunner stays out of scope. Still open:

- Do the host leads agree to swap their current drive sections for MotionCore, starting with CargoMule?
- Can StepClimber's brushed worm gearmotor run from the VESC DC motor mode, or does it need a different power stage? Decided by Amish, 2026-10-02 (MTC-DEC-001): DC motor mode, unless StepClimber's motor needs more current than the controller is rated for.
- Should a dual-motor host such as PalletPilot use two controllers on one supervisor, or two modules? Decided by Amish, 2026-10-02 (MTC-DEC-001): two controllers on one supervisor, with one safety loop and one contactor feeding both.

## User research and co-design

MotionCore's first users are the lab's own host designers, so co-design starts inside the lab.

- [ ] Review Table 1 with each host project and confirm voltage, power, speed and stop needs
- [ ] Walk through the safety loop with a builder who has not seen it and record where it is unclear
- [ ] Ask at least one external maker or repair shop to review the interface and fault chart
- [ ] Revise requirements (MTC-REQ-001) from findings before freezing the interface

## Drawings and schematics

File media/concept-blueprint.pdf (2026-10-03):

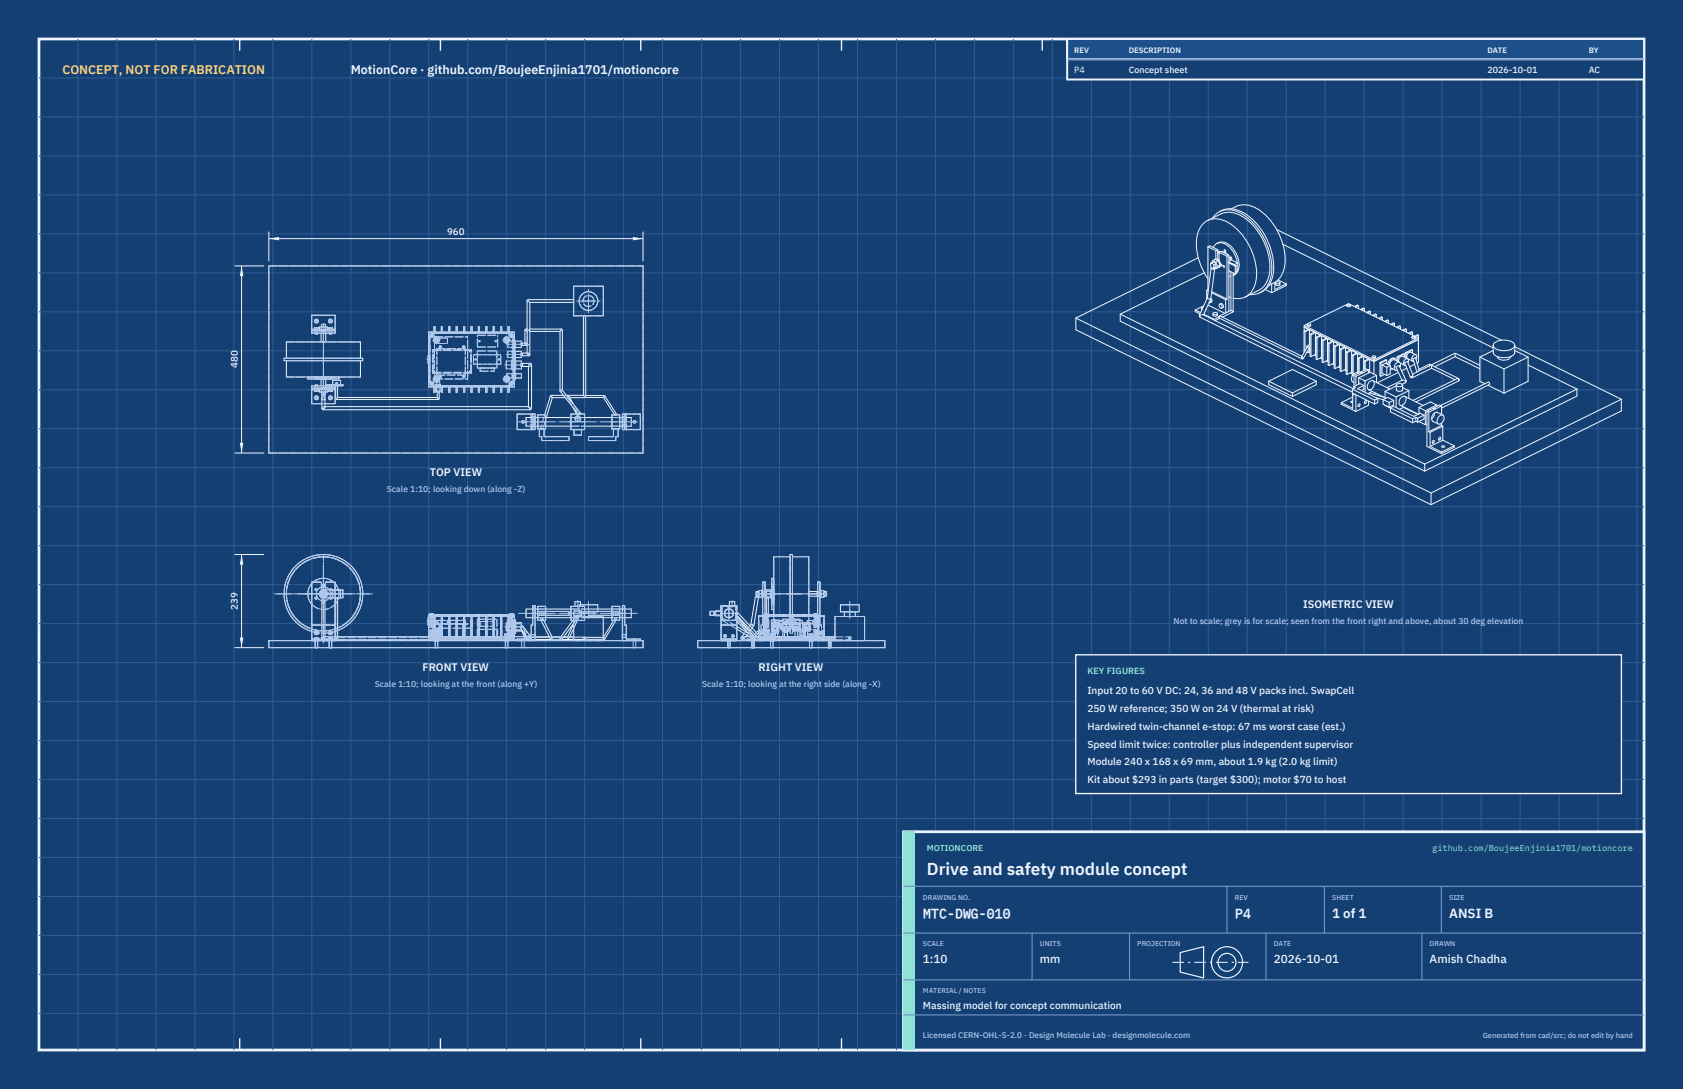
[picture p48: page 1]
CONCEPT, NOT FOR FABRICATION; MotionCore · github.com/BoujeeEnjinia1701/motioncore; FRONT VIEW; TOP VIEW; RIGHT VIEW; ISOMETRIC VIEW; REV; DESCRIPTION; DATE; Concept sheet; MOTIONCORE; github.com/BoujeeEnjinia1701/motioncore; DRAWING NO. MTC-DWG-010; REV P4; SHEET 1 of 1; SIZE ANSI B; SCALE 1:10; UNITS mm; PROJECTION; DRAWN Amish Chadha; Licensed CERN-OHL-S-2.0 · Design Molecule Lab · designmolecule.com; Generated from cad/src; do not edit by hand

Scale 1:10; looking down (along -Z)

Not to scale; grey is for scale; seen from the front right and above, about 30 deg elevation

KEY FIGURES
Input 20 to 60 V DC: 24, 36 and 48 V packs incl. SwapCell
250 W reference; 350 W on 24 V (thermal at risk)
Hardwired twin-channel e-stop: 67 ms worst case (est.)
Speed limit twice: controller plus independent supervisor
Module 240 x 168 x 69 mm, about 1.9 kg (2.0 kg limit)
Kit about $293 in parts (target $300); motor $70 to host

Scale 1:10; looking at the front (along +Y)

Scale 1:10; looking at the right side (along -X)

Drive and safety module concept

MATERIAL / NOTES
Massing model for concept communication

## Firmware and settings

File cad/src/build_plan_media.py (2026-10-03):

"""MotionCore prototype build plan pictures (MTC-BLD-001, STANDARDS section 18).

Run from the repo root:  python cad/src/build_plan_media.py [overview|sheets|layouts|joints|steps|wiring ...]
With no argument it draws everything. Every picture is drawn from cad/src/model.py
(build_components), so the pictures and the model never disagree:
    docs/05-build-plan/overview.png        every component pulled apart, numbered in build order
    cad/drawings/MTC-DWG-101 to 110        making sketches for the made components
    docs/05-build-plan/floor-holes.png     floor plate hole positions
    docs/05-build-plan/wall-holes.png      end wall and side wall hole positions on the finned tube
    docs/05-build-plan/joint-NN.png        close-ups of the joints that need explaining
    docs/05-build-plan/step-NN.png         one picture per assembly step
    docs/05-build-plan/wiring.png          block-level wiring with wire sizes (matplotlib)
Uses .kit/build_views.py. BUILD PLAN ILLUSTRATION, PLAN NOT YET BUILT.
"""
import sys
from pathlib import Path

ROOT = Path(__file__).resolve().parents[2]
sys.path[:0] = [str(ROOT / ".kit"), str(ROOT / "cad" / "src")]
import build_views as bv  # noqa: E402
from build_views import Part  # noqa: E402
from model import PARAMS as P, build_components, derived, floor_holes, connector_holes, bx, fuse  # noqa: E402

OUT = ROOT / "docs" / "05-build-plan"
DWG = ROOT / "cad" / "drawings"
DATE = "2026-10-01"
D = derived(P)
C = build_components(P)
L, W = P["body_l"], P["body_w"]


def part(name, shape, color, explode=(0, 0, 0), alpha=1.0):
    return Part(name, shape, color, None, tuple(explode), alpha)


def S(*keys):
    return fuse([C[k].shape for k in keys])


def pc(key, name=None, explode=(0, 0, 0)):
    c = C[key]
    return part(name or c.name, c.shape, c.color, explode)


def mv(p, e):
    return Part(p.name, p.shape, p.color, None, tuple(e), p.alpha)


# ----------------------------------------------------------------- overview
def overview():
    order = [("floor", "Floor plate", (0, 0, 90)), ("rivnuts", "Rivet nuts (4)", (0, 0, 50)),
             ("tube", "Finned tube", (0, 0, 230)), ("conns", "Sockets: motor, safety loop, command", (120, 20, 230)),
             ("xt90", "Power socket (XT90 in its frame)", (140, -90, 320)), ("ctrl", "Motor controller", (0, 0, 140)),
             ("cont", "Contactor", (0, 0, 150)), ("fuse", "Precharge and fuse block", (0, 60, 150)),
             ("standoffs", "Supervisor standoffs (4)", (0, 0, 330)), ("sup", "Supervisor board", (0, 0, 410)),
             ("gasket", "Lid gasket", (0, 0, 470)), ("lid", "Lid", (0, 0, 520)), ("pads", "Rubber pads (4)", (-70, -60, 0)),
             ("board", "Bench board", (0, 0, -60)), ("uprights", "Motor uprights (2)", (0, 0, 0)),
             ("feet", "Upright feet (2)", (0, 0, -50)), ("ring", "Magnet ring", (0, -150, 180)),
             ("motor", "Reference hub motor", (0, 0, 220)), ("hall_bracket", "Hall bracket and pickup", (0, -150, 0)),
             ("posts", "Bar posts with feet (2)", (0, -40, 0)), ("bar", "Handlebar stub", (0, -120, 20)),
             ("levers", "Brake levers (2)", (0, -200, 30)), ("pod", "Key and throttle pod", (0, -200, 30)),
             ("estop", "E-stop station", (60, 120, 60)), ("harness", "Wiring harness", (220, 120, 0))]
    parts = []
    for k, n, e in order:
        sh = C[k].shape if k != "hall_bracket" else S("hall_bracket", "hall")
        parts.append(part(n, sh, C[k].color, e))
    return bv.overview(parts, OUT / "overview.png", "MotionCore prototype: every component, pulled apart",
                       subtitle="Numbered in build order: the module (1 to 12), the bench rig and devices (13 to 25). "
                                "Seen from the connector end and above", elev=30, azim=-55, size=(12, 8), dpi=150, key=True)


# ----------------------------------------------------------------- making sketches
def sheets():
    import build123d as b
    base = dict(project="MotionCore", date=DATE)
    out = []
    zf, zt = D["z_floor"], D["z_tube"]
    module_ctx = [pc("tube"), pc("rivnuts"), pc("pads")]

    out.append(bv.component_sheet(
        pc("floor"), module_ctx, dwg_no="MTC-DWG-101", title="MotionCore floor plate: making sketch",
        material="Aluminum plate 3 mm, 6061-T6", view_shape=b.Pos(0, 0, -zf) * C["floor"].shape, inset_view=(-35, -60),
        notes=["Cut 220 x 140 mm from 3 mm 6061 plate; square, deburr, corners left square.",
               "Mark from the far end (opposite the sockets) and the socket side;",
               "  the floor holes picture gives every position.",
               "Rivet nut holes 9.0 mm at 20 and 200 from the far end, 20 and 120",
               "  from the socket side (the 180 x 100 mounting pattern).",
               "Corner screw holes 4.5 mm, 7.5 from each edge; countersink from",
               "  below to 8.4 mm so the M4 heads sit flush.",
               "Tapped holes through the plate: M3 (2.5 drill) for the controller (4)",
               "  and the supervisor standoffs (4); M4 (3.3 drill) for the contactor",
               "  foot (2) and the fuse block (2).",
               "Fit: the tube sits on its top face on a film of thermally conductive",
               "  sealant; four M4 countersunk screws go up into the corner ports.",
               "Check: lay the tube on it; the four corner holes line up with the ports."],
        **base))

    tube = C["tube"].shape
    out.append(bv.component_sheet(
        pc("tube"), [pc("floor"), pc("lid"), pc("conns"), pc("xt90")], dwg_no="MTC-DWG-102",
        title="MotionCore finned tube: making sketch", material="Bought finned enclosure extrusion, 220 x 140 mm, 3 mm walls",
        view_shape=b.Pos(0, 0, -zt) * tube, inset_view=(28, -40),
        notes=["Cut 56 mm off the extrusion, square to its length, so the fins stand",
               "  upright. Face both cut ends flat; deburr; keep the ports clean.",
               "The four corner ports are part of the extrusion; tap them M4 from",
               "  both ends, 12 mm deep (they take the floor and lid screws).",
               "Connector end wall (short wall, holes 28.5 above the bottom edge,",
               "  measured from the socket side's outer face): XT90 slot 12 x 22 at",
               "  28 with two 3.2 holes 14.5 above and below; motor 20.5 hole at 56;",
               "  safety loop 16.5 hole at 83 and command 16.5 hole at 109, each with",
               "  four 3.2 holes on a 15 mm square.",
               "Socket side: speed socket 8.5 hole between the 1st and 2nd fins from",
               "  the far end, 24.5 from that end, 18 above the bottom edge.",
               "Far end wall: vent hole 5 mm on the centre line, 43 above the bottom.",
               "Check: each socket seats flat; nothing fouls a port or a fin."],
        **base))

    sx0, sx1, sy0, sy1, szb, _ = P["supervisor"]
    pcb = bx(sx0, sx1, sy0, sy1, zt + szb, zt + szb + 1.6)
    for x, y in P["sup_standoffs"]:
        pcb = pcb - b.Pos(x, y, zt + szb + 0.8) * b.Cylinder(1.6, 4)
    sup = pcb
    out.append(bv.component_sheet(
        pc("sup", "Supervisor carrier board"), [pc("standoffs"), pc("ctrl"), pc("floor")], dwg_no="MTC-DWG-103",
        title="MotionCore supervisor carrier board: making sketch", material="FR4 perforated board 1.6 mm, 2.54 mm pitch",
        view_shape=b.Pos(0, 0, -(zt + 35)) * sup, inset_view=(35, -50),
        notes=["Cut 85 x 108 mm from 1.6 mm FR4 perforated board.",
               "Four 3.2 mm holes for the standoffs: 15 and 75 mm from the edge",
               "  nearest the far end, 6 and 82 mm from the socket-side edge.",
               "The prototype supervisor is built from modules on this board (see",
               "  the wiring picture): microcontroller board with two CAN controllers,",
               "  two CAN transceivers, 18 to 75 V in, 12 V out buck, coil switch,",
               "  precharge switch, input conditioning for the speed, brake and",
               "  e-stop B signals, and a USB socket for the fault log.",
               "Coil economizer module (24 x 14 x 8): in the extra strip along the edge",
               "  away from the sockets, 9 to 33 from the far end, 91 to 105 from the",
               "  socket-side edge.",
               "Keep all modules inside a 73 x 68 mm area in the middle so the",
               "  modules clear the lid by 10 mm and the four standoff screws.",
               "Fit: four M3 screws into 35 mm hex standoffs; the board sits over",
               "  the controller with 10 mm of air between them.",
               "Check: board flat; no solder tail longer than 2 mm underneath."],
        rev="P2", revisions=[("P1", "Making sketch for the prototype build plan", "2026-10-01", "AC"),
                             ("P2", "Board lengthened to 108 mm for the coil economizer", "2026-10-02", "AC")],
        **base))

    out.append(bv.component_sheet(
        pc("lid"), [pc("tube"), pc("gasket"), pc("floor")], dwg_no="MTC-DWG-104",
        title="MotionCore lid and lid gasket: making sketch", material="Aluminum sheet 3 mm, 5052 or 6061; EPDM sheet 1 mm",
        view_shape=b.Pos(0, 0, -D["z_lid"]) * C["lid"].shape, inset_view=(35, -60),
        notes=["Lid: cut 220 x 140 mm from 3 mm sheet; deburr; round the corners",
               "  to about 1 mm. Four 4.5 mm holes, 7.5 mm in from each end and side.",
               "Gasket: cut from 1 mm closed-cell EPDM sheet, 220 x 140 mm outside,",
               "  a 3 mm wide frame (the wall thickness), with a 12 mm round pad at",
               "  each corner over the port and a 4.5 mm hole through each pad.",
               "Use the lid as the template for the gasket's four holes.",
               "Fit: gasket on the top of the tube, lid on the gasket, four M4 x 10",
               "  button-head screws with bonded sealing washers into the ports.",
               "Tighten evenly in a cross pattern until the gasket is squeezed",
               "  to about two-thirds of its thickness; do not crush it.",
               "Check: lid sits flat; no gap you can see round the edge."],
        **base))

    out.append(bv.component_sheet(
        pc("board"), [pc("tube"), pc("uprights"), pc("posts"), pc("estop"), pc("motor")], dwg_no="MTC-DWG-105",
        title="MotionCore bench board: making sketch", material="Plywood 18 mm, exterior grade",
        view_shape=b.Pos(0, 0, P["board"][4] / 2) * C["board"].shape, inset_view=(35, -60),
        notes=["Cut 960 x 480 mm from 18 mm plywood; sand the edges; mark the",
               "  left end (motor end) and the front edge (the brake lever side).",
               "Module bolts: four 6.5 mm holes on a 180 x 100 mm rectangle, centred",
               "  520 mm from the left end and 240 mm from the front edge.",
               "Motor upright feet: four 6.6 mm holes at 122 and 158 mm from the",
               "  left end, 141.5 and 338.5 mm from the front edge.",
               "Bar post feet: two 6.6 mm holes 80 mm from the front edge, at 652",
               "  and 938 mm from the left end.",
               "E-stop station: fixed with wood screws through its base, centred",
               "  820 mm from the left end and 390 mm from the front edge.",
               "Counterbore the bolt holes from below 13 mm, 3 mm deep, so the",
               "  board sits flat on the bench.",
               "Check: the module's rubber pads land on the four 6.5 mm holes."],
        **base))

    up = C["uprights"].shape & bx(P["motor_x"] - 40, P["motor_x"] + 40, -80, -60, -1, 160)
    out.append(bv.component_sheet(
        part("Motor upright", up, C["uprights"].color), [pc("motor"), pc("feet"), pc("hall_bracket")],
        dwg_no="MTC-DWG-106", title="MotionCore motor upright (make 2): making sketch",
        material="Aluminum flat bar 60 x 6 mm, 6082 or 6061", inset_view=(20, -35),
        view_shape=up,
        notes=["Cut two 150 mm lengths of 60 x 6 mm bar; square and deburr.",
               "Axle slot: 10.2 mm wide on the centre line, 36 mm deep from the top",
               "  end, flat bottom. The axle flats (10 mm) slide in from above and",
               "  its centre sits 120 mm above the board. Saw both sides, file square.",
               "Foot bolt holes: two 6.6 mm, 20 mm up, 18 mm each side of centre.",
               "The upright on the socket side of the motor (the one nearer the",
               "  front edge) also gets two 4.4 mm holes for the Hall bracket,",
               "  120 mm up, 12 and 20 mm from centre toward the module.",
               "Fit: inside faces 135 mm apart (the motor's axle width); feet bolted",
               "  to the outside faces; axle nut and washer outside each upright.",
               "Check: the motor's axle drops into both slots by hand and cannot turn."],
        **base))

    foot = C["feet"].shape & bx(P["motor_x"] - 40, P["motor_x"] + 40, -120, -70, -1, 50)
    out.append(bv.component_sheet(
        part("Upright foot", foot, C["feet"].color), [pc("uprights"), pc("motor")], dwg_no="MTC-DWG-107",
        title="MotionCore upright foot (make 4: two 60 mm, two 40 mm): making sketch",
        material="Aluminum equal angle 40 x 40 x 4 mm", inset_view=(25, -35), view_shape=foot,
        notes=["Cut two 60 mm lengths (motor uprights) and two 40 mm lengths (bar",
               "  posts) of 40 x 40 x 4 angle; square and deburr.",
               "60 mm feet, upright leg: two 6.6 mm holes 20 mm up from the board",
               "  side, 18 mm each side of centre. Flat leg: two 6.6 mm holes",
               "  25 mm from the outside corner, 18 mm each side of centre.",
               "40 mm feet, upright leg: two 6.6 mm holes 12 mm up, 10 mm each side",
               "  of centre. Flat leg: one 6.6 mm hole 25 mm from the outside",
               "  corner, on the centre.",
               "Drill each foot clamped to its upright or post so the holes match.",
               "Fit: the upright leg lies flat on the outside face of the upright or",
               "  post; the flat leg lies on the board and points away from it;",
               "  M6 bolts with washers and nyloc nuts, the board bolts from below.",
               "Check: upright or post stands square to the board."],
        **base))

    out.append(bv.component_sheet(
        pc("hall_bracket"), [part("Upright", C["uprights"].shape & bx(-450, -300, -80, -60, -1, 160), C["uprights"].color), pc("hall"), pc("ring")], dwg_no="MTC-DWG-108",
        title="MotionCore Hall pickup bracket: making sketch", material="Aluminum flat bar 20 x 3 mm",
        inset_view=(55, -120),
        notes=["Cut 42 mm of 20 x 3 mm flat bar; deburr.",
               "Two 4.4 mm holes on the centre line, 4 and 12 mm from one end:",
               "  these bolt to the socket-side upright with M4 bolts.",
               "The Hall pickup sits on the other end, its centre 26 mm from the",
               "  bolted end; mark its lug holes through the pickup and drill to",
               "  suit (usually two M3).",
               "Fit: the bracket lies flat on the inside face of the upright,",
               "  level with the axle, and reaches toward the module. The pickup's",
               "  face is 3.5 mm from the magnet ring, at the ring's magnet circle",
               "  (34 mm from the axle centre).",
               "Check: spin the wheel by hand; the ring passes the pickup without",
               "  touching and the gap is 3 to 4 mm all round."],
        **base))

    post = C["posts"].shape & bx(150, 170, -190, -130, -1, 100)
    post = post & bx(157.01, 162.99, -190, -130, -1, 100)
    out.append(bv.component_sheet(
        part("Bar post", post, C["posts"].color), [pc("bar"), pc("levers"), pc("pod")], dwg_no="MTC-DWG-109",
        title="MotionCore bar post (make 2): making sketch", material="Aluminum flat bar 40 x 6 mm, 6082 or 6061",
        inset_view=(25, -60), view_shape=post,
        notes=["Cut two 90 mm lengths of 40 x 6 mm bar; square and deburr.",
               "Bar hole: 22.5 mm on the centre line, centre 70 mm up from the",
               "  board end. Drill a pilot, open with a step drill or hole saw,",
               "  file to a sliding fit on the 22.2 mm handlebar.",
               "Grub screw: drill 4.2 mm down the centre line from the top end",
               "  into the bar hole and tap M5; an M5 grub screw locks the bar.",
               "Foot bolt holes: two 6.6 mm, 12 mm up, 10 mm each side of centre.",
               "Fit: a 40 mm foot bolts to the outside face of each post; the posts",
               "  stand 230 mm apart (centres) with the bar through both.",
               "Check: the bar slides through both posts by hand and locks with",
               "  the grub screws."],
        **base))

    out.append(bv.component_sheet(
        pc("bar"), [pc("posts"), pc("levers"), pc("pod")], dwg_no="MTC-DWG-110",
        title="MotionCore handlebar stub: making sketch", material="Aluminum tube 22.2 mm outside, 2 mm wall",
        inset_view=(25, -60),
        notes=["Cut 270 mm of 22.2 mm (7/8 in) aluminum tube, square.",
               "Deburr inside and out and chamfer both outside edges 0.5 mm so",
               "  the lever and pod clamps slide on without scoring.",
               "Fit: through both bar posts, 70 mm above the board, ends standing",
               "  10 mm out from each post. From the left: brake lever, pod, brake",
               "  lever, each clamped with its own screw.",
               "Lock it with the two M5 grub screws in the posts.",
               "Check: the clamps tighten without the bar turning in the posts."],
        **base))
    return out
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

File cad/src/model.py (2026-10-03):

"""MotionCore parametric model (build123d), TRL 3, constructable design (MTC-DDR-003).

Run from the repo root:
    python cad/src/model.py            export STEP and STL, print envelopes and run the checks
    python cad/src/model.py --check    constructability checks only (overlaps, contacts, clearances)

The prototype is the MotionCore module bolted to a plywood bench board through its host mounting
interface, with the reference hub motor held by its axle in two slotted uprights (wheel off the
board), the e-stop station screwed to the board and the brake levers and the key and throttle pod
clamped on a short handlebar stub. Every component can be cut, drilled, bent or bought, and every
joint has a fixing (MTC-DDR-003 lists the changes from the concept model).

Axes: X along the module length (connector end on +X), Y across the fins, Z up. Units mm.
Bench board top at Z = 0. The module is centred on the origin in X and Y.
"""
from __future__ import annotations

import math
import sys
from dataclasses import dataclass
from pathlib import Path

# Top-level parameters (mm). Edit these, not the geometry below.
PARAMS = {
    # Enclosure (MTC-PRC-001, R12). body_h = floor plate + finned tube.
    "body_l": 220.0, "body_w": 140.0, "body_h": 59.0, "wall": 3.0,
    "floor_t": 3.0,              # 6061 plate under the tube, thermally conductive sealant film between
    "lid_t": 3.0, "gasket_t": 1.0,
    "fin_n": 11, "fin_pitch": 19.0, "fin_t": 3.0, "fin_depth": 14.0,
    "fin_z0": 3.0, "fin_z1": 59.0,          # fin span from the body underside: the full tube height
    "port_r": 4.5, "port_hole": 3.3,        # screw ports in the tube's inside corners, tapped M4
    # Host mounting interface: four M6 closed-end rivet nuts in the floor plate on rubber pads
    "mount_px": 180.0, "mount_py": 100.0, "pad_d": 16.0, "pad_h": 3.0, "rivnut_flange": (13.0, 1.0),
    "rivnut_body": (9.0, 13.0),             # diameter, height above the floor
    # Connectors in the +X end wall (interface v0.1, plus the speed sensor socket)
    "panel_t": 0.0, "panel_w": 102.0, "panel_z0": 14.0, "panel_z1": 52.0,
    "conn_len": 18.0, "conn_z": 31.5,       # protrusion outside the wall; centre height above the body underside
    "xt90": (-42.0, 11.0, 21.0),            # y, width (Y), height (Z): XT90 stood on end in a panel frame 18 x 34
    "conns": [("motor", -14.0, 10.0), ("safety", 13.0, 8.0), ("command", 39.0, 8.0)],
    "motor_flange": 13.0, "motor_nut_af": 24.0, "m12_flange": 20.0,
    "speed_socket": (-85.5, 21.0),          # x on the -Y wall between two fins; height above the body underside
    "vent_z": 46.0,                         # adhesive membrane vent on the -X end wall
    # Internal parts (x0, x1, y0, y1, z0 above the floor top, height)
    "controller": (-100.0, 0.0, -35.0, 25.0, 1.0, 24.0),   # VESC class, 75 V stage, on a 1 mm thermal pad
    "supervisor": (-95.0, -10.0, -50.0, 58.0, 35.0, 10.0),  # board on 35 mm standoffs, outside the controller; 20 mm longer on +Y for the economizer (MTC-DEC-001, 2026-10-02)
    "economizer": (-86.0, -62.0, 41.0, 55.0, 8.0),          # coil economizer module on the carrier board: x0, x1, y0, y1, height above the board
    "sup_standoffs": [(-80.0, -44.0), (-20.0, -44.0), (-80.0, 32.0), (-20.0, 32.0)],
    "contactor": (15.0, 65.0, -22.0, 22.0, 3.0, 45.0),     # on a 3 mm mounting foot
    "contactor_foot": (5.0, 75.0, -12.0, 12.0),
    "fuseblock": (15.0, 67.0, 32.0, 62.0, 0.0, 22.0),      # precharge resistor and fuse holder, beside the contactor
    # Bench rig (prototype only, BOM line 15)
    "board": (-520.0, 440.0, -240.0, 240.0, 18.0),
    "motor_x": -380.0, "motor_d": 190.0, "motor_w": 90.0, "axle_l": 180.0, "axle_z": 120.0, "axle_flats": 10.0,
    "upright": (60.0, 6.0, 150.0), "upright_gap": 135.0,  # flat bar width, thickness, height; inside spacing
    "foot": (40.0, 4.0, 60.0),               # equal angle leg, thickness, length
    "ring": (18.0, 40.0, 5.0), "ring_pcd": 44.0,
    "hall": (20.0, 11.0, 20.0), "hall_gap": 3.5,
    "bar": (22.2, 270.0, 140.0, -160.0, 70.0),   # handlebar stub OD, length, x start, y, z
    "post": (40.0, 6.0, 90.0), "post_x": (160.0, 390.0),
    "pod_x": (255.0, 290.0), "levers_x": (180.0, 370.0),
    "estop_xy": (300.0, 150.0), "estop_box": 76.0, "estop_h": 62.0, "estop_head_d": 48.0,
}


@dataclass
class Comp:
    """One component: a single made or bought piece (or a matched set of fixings)."""
    name: str
    shape: object
    bom: int | None
    kind: str            # "made", "bought" or "fixing"
    color: str


# ------------------------------------------------------------------ geometry helpers
def _b3d():
    import build123d as b
    return b


def bx(x0, x1, y0, y1, z0, z1):
    b = _b3d()
    return b.Pos((x0 + x1) / 2, (y0 + y1) / 2, (z0 + z1) / 2) * b.Box(abs(x1 - x0), abs(y1 - y0), abs(z1 - z0))


def zcyl(x, y, z, r, h):
    b = _b3d()
    return b.Pos(x, y, z) * b.Cylinder(r, h)


def ycyl(x, y, z, r, h):
    b = _b3d()
    return b.Pos(x, y, z) * b.Rot(90, 0, 0) * b.Cylinder(r, h)


def xcyl(x, y, z, r, h):
    b = _b3d()
    return b.Pos(x, y, z) * b.Rot(0, 90, 0) * b.Cylinder(r, h)


def hexprism(axis, x, y, z, af, h):
    b = _b3d()
    s = b.extrude(b.RegularPolygon(af / math.sqrt(3), 6), h / 2, both=True)
    rot = {"z": b.Rot(0, 0, 0), "y": b.Rot(90, 0, 0), "x": b.Rot(0, 90, 0)}[axis]
    return b.Pos(x, y, z) * rot * s


def fuse(shapes):
    out = None
    for s in shapes:
        if s is None:
            continue
        out = s if out is None else out + s
    return out


def _tube(a, c, r):
    b = _b3d()
    a = b.Vector(*a); c = b.Vector(*c); d = c - a
    return b.Solid.make_cylinder(r, d.length, b.Plane(origin=a, z_dir=d.normalized()))


def _path(points, r):
    """A cable: straight runs with a ball at each bend so the runs join."""
    b = _b3d()
    s = None
    for a, c in zip(points, points[1:]):
        t = _tube(a, c, r)
        s = t if s is None else s + t
    for q in points[1:-1]:
        s = s + b.Pos(*q) * b.Sphere(r)
    return s
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

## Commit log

2026-09-25 Initial scaffold: standard open hardware layout, CERN-OHL-S v2 + MIT licenses
    Claude-Session: https://claude.ai/code/session_01XuhhSU4W6fYhgCfURbrkut
    [bom.csv]
2026-09-25 Populate to TRL 2: problem, requirements, precis, concept media, BOM and README use cases
    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
    [bom.csv]
2026-09-26 Advance to TRL 3: DDR-001, CAL-001 sizing, parametric model with STEP/STL, GA drawing, priced BOM; TRL 4 on hold
    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
    [bom.csv, motioncore-enclosure.step, motioncore-enclosure.stl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]
2026-09-26 Accept all recommendations (DDR-002), switch footer to designmolecule.com, add README write-up with new inspiration point
    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
    [bom.csv, motioncore-enclosure.step, motioncore-kit.step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]
2026-09-27 Product appearance model and photoreal renders
    Adds cad/src/product_model.py (appearance model for renders only, all main
    dimensions from model.py) and Blender renders in media/render-*.png,
    captioned with the project, repository and viewing direction. README leads
    with the product render; trl stays 3.
    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
2026-10-01 Image quality pass: legible exploded views, flow diagrams and drawing sheets
    Kit 1.6.1 image layout: the parts list sits in its own column, number bubbles sit on visible parts and never overlap, small parts get a leader, pictures are cropped to the subject, flow labels keep numbers with their units, and sheet captions and the revision table no longer overprint. Concept images, blueprint and general arrangement sheet regenerated; repo-specific labels moved clear of other text and lines.
2026-10-01 Kit 1.7.0: constructable design, illustrated build plan and design decisions register
    The design is now constructable: every part can be made and fits its neighbours, with each change recorded in a Design for construction decision record (made under Amish's 2026-09-30 instruction; ope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
    FlexHand also credits Dr. Geeti Chadha as a contribut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
    [bom.csv, motioncore-enclosure.step, motioncore-enclosure.stl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]
2026-10-02 Record Amish's approval of the open-decision recommendations
    Amish approved the recommendation on every open decision in the design decisions register ("i approve your recommendations for all 555 open decisions.", 2026-10-02). Each decision is moved to Decisio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
2026-10-03 Carry approved follow-ups into the design and redo photoreal renders
    Amish approved the follow-up actions from the open-decision sign-off ("APPROVED CHANGES, COMPLETE THESE", 2026-10-02), the design-for-construction change tables in ten repos, the last wave's open dec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
    [bom.csv, motioncore-enclosure.step, motioncore-kit.step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]

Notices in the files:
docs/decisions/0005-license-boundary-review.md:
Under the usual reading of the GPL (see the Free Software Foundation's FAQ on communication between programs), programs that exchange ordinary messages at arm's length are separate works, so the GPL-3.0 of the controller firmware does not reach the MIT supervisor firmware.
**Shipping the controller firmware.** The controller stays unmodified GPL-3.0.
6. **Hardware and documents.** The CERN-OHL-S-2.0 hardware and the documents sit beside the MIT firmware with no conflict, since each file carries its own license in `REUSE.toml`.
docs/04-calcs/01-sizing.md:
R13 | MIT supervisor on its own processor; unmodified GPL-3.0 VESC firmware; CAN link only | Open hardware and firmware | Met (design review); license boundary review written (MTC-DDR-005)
